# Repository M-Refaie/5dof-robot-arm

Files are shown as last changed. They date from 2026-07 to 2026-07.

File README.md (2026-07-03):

# 5-DOF Visual-Inspection Robotic Arm

A 5-degree-of-freedom robotic arm for automated visual inspection, combining servo-actuated joints, a rack-and-pinion rotating base (270° coverage), and an ESP32-CAM end-effector that recognizes targets on-device. Built end-to-end: mechanical design, custom electronics, kinematics & control, and an embedded AI vision model.

> Team project at Ain Shams University (Mechatronic System Design / Industrial Robotics, 2025). See *Credits*.

---

## Demo
▶ **[Watch the real arm run the full integrated system (video)](https://drive.google.com/file/d/1G8d9McYiD0UEVgwIUuDRzAie-aXbsvC7/view)**

Simulation (MATLAB / Simscape Multibody):
- ▶ [Inspection motion around the product](docs/sim_inspection_motion.mp4)
- ▶ [Forward-kinematics Simscape model](docs/sim_forward_kinematics.mp4)

## Highlights
- **5-DOF manipulator** — servo joints + rack-and-pinion base giving **270° rotation** around the inspected product.
- **On-device AI vision** — an **Edge Impulse** model deployed on an **ESP32-CAM** recognizes **15 letter targets** under varying angle and lighting.
- **Closed-loop PID** joint control, tunable **in real time via Arduino IoT Cloud** (live Kp/Ki/Kd, setpoint, and angle feedback on a dashboard).
- **Full kinematics in MATLAB** — forward & inverse kinematics, joint-space trajectory planning, and rigid-body-tree modeling (Simulink + Peter Corke Robotics Toolbox).
- **Custom hardware** — designed PCBs, 3D-printed joints/holders, and actuator sizing validated against MATLAB torque simulation.

## Tech stack
**Modeling & control:** MATLAB, Simulink, Peter Corke Robotics Toolbox, PID
**Embedded:** Arduino (C/C++), ESP32, ESP32-CAM, Arduino IoT Cloud
**AI/vision:** Edge Impulse (on-device inference)
**Hardware:** Autodesk Inventor (CAD), custom PCB, 3D printing
**Actuators/drivers:** DC motors w/ encoders (JGB-520), MG996 servos, L298N (DC), PCA9685 (servo)

## Robot parameters (standard DH)
| Joint | θ | d (mm) | a (mm) | α |
|---:|:--:|:---:|:---:|:----:|
| 1 | θ₁ | 65 | 277 | 90° |
| 2 | θ₂ | −37.5 | 192 | 0° |
| 3 | θ₃ | 17.5 | 172 | −90° |
| 4 | θ₄ | 0 | 62.5 | 90° |
| 5 | θ₅ | 0 | 45 | 0° |

## Repository structure
```
matlab/
├── peter_corke/        # forward/inverse kinematics (Peter Corke Toolbox)
├── simscape_sim/       # Simscape robot model + data files
└── simulink_control/   # cascaded control, DAQ, ESP32 motor block
firmware/
├── controlWithPot/       # PID joint control from a potentiometer setpoint
├── controlWithSetpoint/  # PID joint control from a fixed setpoint
└── arduino_iot_cloud/    # full ESP32 app: servo + DC PID + Arduino IoT Cloud dashboard
hardware/               # custom PCBs (Fritzing): base, DC, servo
docs/                   # dashboard screenshot
```

## Implementation
Key parts of the build:
- **Forward & inverse kinematics** and **joint-space trajectory planning** (Simulink + Peter Corke Robotics Toolbox), with rigid-body-tree modeling.
- **PID control** — designed/simulated in MATLAB/Simulink **and** implemented in Arduino firmware (encoder feedback + H-bridge, `PID_v1`).
- **Actuator sizing** from MATLAB torque simulation (RMS torque vs. selected motors/servos).
- **Custom PCB design** integrating the microcontroller, motor drivers (L298N / PCA9685), and power.
- **Integrated ESP32 application** tying the servo and DC-motor PID control together with a live Arduino IoT Cloud dashboard (`firmware/arduino_iot_cloud/`).

## Live control dashboard (Arduino IoT Cloud)
The arm connects to an **Arduino IoT Cloud** dashboard for live monitoring and tuning: the PID gains (Kp/Ki/Kd for both DC joints), servo and DC-motor setpoints, live joint-angle gauges, limit-switch status, and an automatic/manual mode switch, all adjustable in real time while the arm runs.

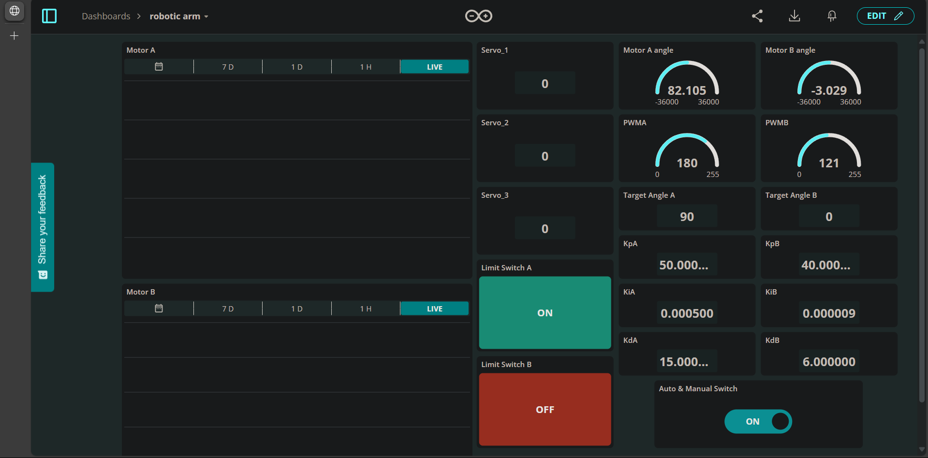
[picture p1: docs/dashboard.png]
Arduino IoT Cloud dashboard


Firmware in [`firmware/arduino_iot_cloud/`](firmware/arduino_iot_cloud): open `Main_Code.ino`, fill your network and device credentials into `arduino_secrets.h`, select the ESP32 board, and flash.

## Design (CAD)
The full test rig: the arm sits on a 270° curved rack that carries it around the inspected product, with the electronics box and power supply alongside.

| Full assembly | Inspection pose | End-effector |
|:--:|:--:|:--:|
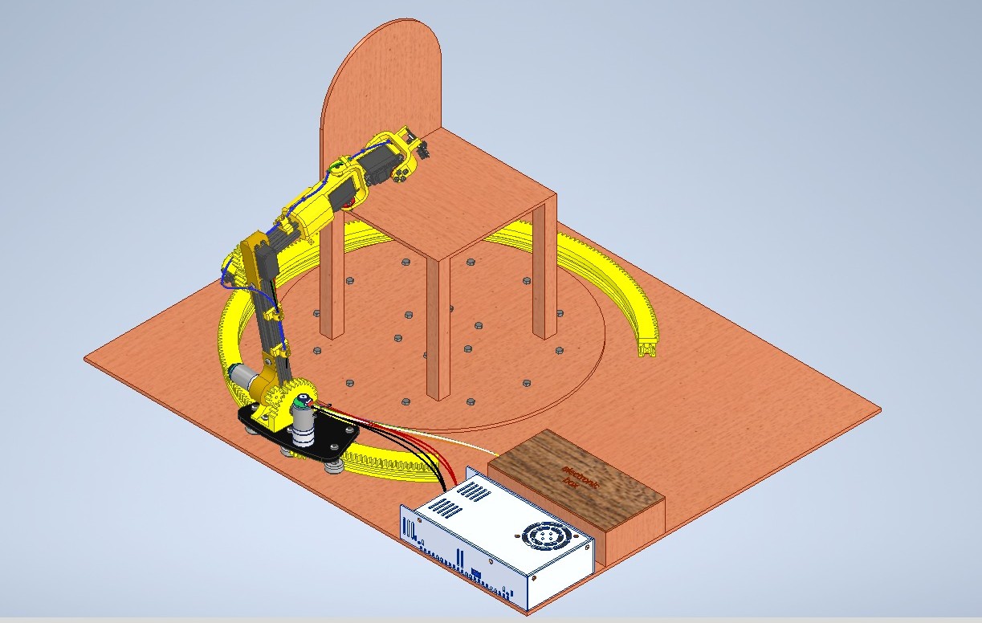
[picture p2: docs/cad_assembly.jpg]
Full CAD assembly of the arm and its test rig
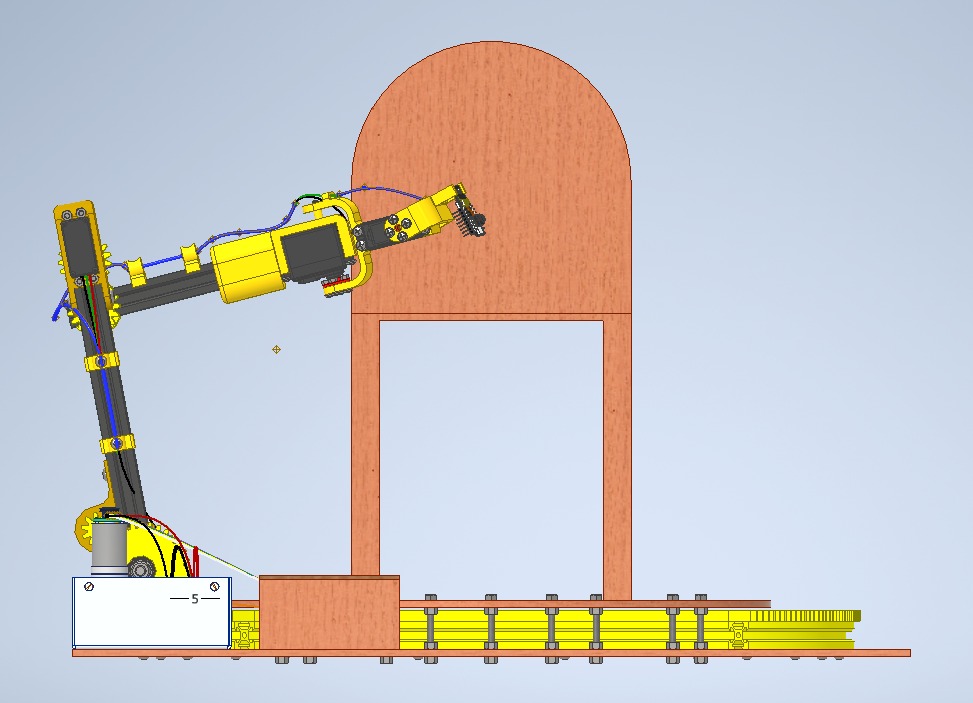
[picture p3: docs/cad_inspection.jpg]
Arm reaching an inspection pose
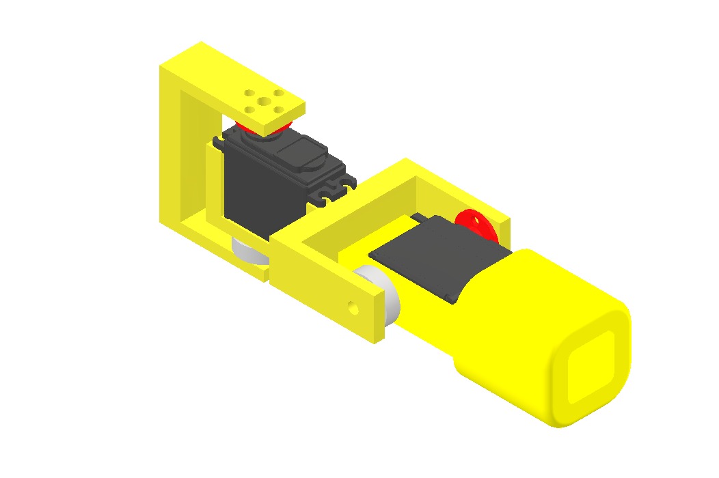
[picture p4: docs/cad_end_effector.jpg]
Wrist and ESP32-CAM end-effector
|  |  |  |

## Results
- 270° inspection sweep with repeatable joint positioning under PID control.
- On-device letter recognition across 15 classes (dataset reduced from 28→15 to fit the ESP32-CAM memory budget while keeping accuracy).

## How to run
- **MATLAB:** install the Peter Corke Robotics Toolbox, open `matlab/`, run the FK/IK scripts and the Simulink model.
- **Firmware:** open a sketch in `firmware/` in Arduino IDE (the full app is `firmware/arduino_iot_cloud/Main_Code.ino`), fill in `arduino_secrets.h`, select the ESP32 board, and flash.

## Credits
Team project at Ain Shams University (Mechatronics, 2025): Mohamed Refaie, Mina Ashraf, Mario Medhat, Mazen Mohamed, and Mariam Mahmoud.

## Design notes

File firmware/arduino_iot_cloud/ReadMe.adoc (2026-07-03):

:Author: mms13
:Email:
:Date: 01/05/2025
:Revision: version#
:License: Public Domain

= Project: {Project}

Describe your project

== Step 1: Installation
Please describe the steps to install this project.

For example:

1. Open this file
2. Edit as you like
3. Release to the World!

== Step 2: Assemble the circuit

Assemble the circuit following the diagram layout.png attached to the sketch

== Step 3: Load the code

Upload the code contained in this sketch on to your board

=== Folder structure

....
 sketch123                => Arduino sketch folder
  ├── sketch123.ino       => main Arduino file
  ├── schematics.png      => (optional) an image of the required schematics
  ├── layout.png          => (optional) an image of the layout
  └── ReadMe.adoc         => this file
....

=== License
This project is released under a {License} License.

=== Contributing
To contribute to this project please contact: 

=== BOM
Add the bill of the materials you need for this project.

|===
| ID | Part name      | Part number | Quantity
| R1 | 10k Resistor   | 1234-abcd   | 10       
| L1 | Red LED        | 2345-asdf   | 5        
| A1 | Arduino Zero   | ABX00066    | 1        
|===

=== Help
This document is written in the _AsciiDoc_ format, a markup language to describe documents. 
If you need help you can search the http://www.methods.co.nz/asciidoc[AsciiDoc homepage]
or consult the http://powerman.name/doc/asciidoc[AsciiDoc cheatsheet]

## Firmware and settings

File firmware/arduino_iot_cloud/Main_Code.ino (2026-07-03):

#include "arduino_secrets.h"
#include <Arduino.h>
#include "thingProperties.h"
#include <ESP32Servo.h>
#include <Wire.h>
#include <Adafruit_PWMServoDriver.h>

// Initialize the PWM Servo Driver at address 0x40
Adafruit_PWMServoDriver board1 = Adafruit_PWMServoDriver(0x40);

// Define the pulse range for each servo
int SERVOMIN[3] = {105,150,150}; // Minimum pulse length count (out of 4096)
int SERVOMAX[3] = {500,460,420}; // Maximum pulse length count (out of 4096)
int SERVORANGE[3] = {180,180,90}; // Servo angle range for each servo

#define SERVO_FREQ 50 // Frequency of the servos (50 Hz)

// Pin Definitions for limit switches
const int limitSwitchPinA = 2; 
const int limitSwitchPinB = 15; 
bool HomedA = 0; // Flag to check if Motor A has been homed
bool HomedB = 0; // Flag to check if Motor B has been homed

// Servo angles (initial values)
int angle1 = 90;  
int angle2 = 90;
int angle3 = 00;
const int angleinil = 90; // Initial servo angle

// Motor A Pins (DC Motor A)
static const int PWM_PIN_A = 18;
static const int IN1_PIN_A = 25;
static const int IN2_PIN_A = 26;
static const int ENCA_PIN_A = 35;
static const int ENCB_PIN_A = 34;

// Motor B Pins (DC Motor B)
static const int PWM_PIN_B = 19;
static const int IN1_PIN_B = 27;
static const int IN2_PIN_B = 14;
static const int ENCA_PIN_B = 33; 
static const int ENCB_PIN_B = 32; 

// PWM Configuration
#define CH_A 0
#define CH_B 1  
const uint32_t LEDC_FREQ = 5000; // Frequency for PWM signals
const int LEDC_RES = 8; // Resolution of PWM

// PID Variables
volatile long encoderPosA = 0, encoderPosB = 0; // Encoder positions for motors A and B
long prevMicros = 0; // Previous time for PID calculation
float prevErrorA = 0, prevErrorB = 0; // Previous error for PID
float integralA = 0, integralB = 0; // Integral error for PID

// Target & Conversion
const float PULSES2DEG_A = 180.0 / 11560.0;  // Conversion factor for Motor A
const float PULSES2DEG_B = 1296.0 / 22253.0; // Conversion factor for Motor B

// Motor Related Variables
int dirA; // Direction of Motor A
int dirB; // Direction of Motor B
float angleA; // Current angle of Motor A
float angleB; // Current angle of Motor B
long pulsesA; // Pulses for Motor A
long pulsesB; // Pulses for Motor B
int pwmA; // PWM value for Motor A
int pwmB; // PWM value for Motor B
float errorA; // Error for Motor A PID
float errorB; // Error for Motor B PID
float dA; // Derivative term for Motor A PID
float dB; // Derivative term for Motor B PID
float dt; // Time difference for PID
float uA; // Control output for Motor A PID
float uB; // Control output for Motor B PID

// Encoder Interrupt Service Routines (ISRs)
void IRAM_ATTR readEncoderA() {
    if (digitalRead(ENCB_PIN_A) == digitalRead(ENCA_PIN_A)) encoderPosA++;
    else encoderPosA--;  // Update encoder position for Motor A based on the direction
}

void IRAM_ATTR readEncoderB() {
    if (digitalRead(ENCB_PIN_B) == digitalRead(ENCA_PIN_B)) encoderPosB++;
    else encoderPosB--;  // Update encoder position for Motor B based on the direction
}

void IRAM_ATTR stopMotorA() {
    driveMotor(CH_A, IN1_PIN_A, IN2_PIN_A, 0, 0); 
    encoderPosA = 0; // Reset encoder position for Motor A
    angleA = 0; // Reset angle for Motor A
    currentAngle1 = 0; // Reset current angle for Servo 1
}

void IRAM_ATTR stopMotorB() {
    driveMotor(CH_B, IN1_PIN_B, IN2_PIN_B, 0, 0); 
    encoderPosB = 0; // Reset encoder position for Motor B
    angleB = 0; // Reset angle for Motor B
    currentAngle2 = 0; // Reset current angle for Servo 2
}

// Motor Driver Function to control direction and speed
void driveMotor(int pwmChannel, int in1, int in2, int dir, int pwmVal) {
  ledcWrite(pwmChannel, pwmVal); // Set the PWM value
  if (dir > 0) { // Forward direction
    digitalWrite(in1, LOW); 
    digitalWrite(in2, HIGH);
  }
  else if (dir < 0) { // Reverse direction
    digitalWrite(in1, HIGH);
    digitalWrite(in2, LOW);
  }
  else { // Stop the motor
    digitalWrite(in1, HIGH);
    digitalWrite(in2, HIGH);
  }
}

// Function to convert servo angle to PWM pulse width
void SetServoAngle(int servonum, int angle){
  board1.setPWM((servonum+8), 0, map(angle, 0, SERVORANGE[servonum], SERVOMIN[servonum], SERVOMAX[servonum]));
}

//////////////////////////\\\\\\\\\\\\\\\\\\\\\\\\\\
///////////////////// Scenario \\\\\\\\\\\\\\\\\\\\
//////////////////////////\\\\\\\\\\\\\\\\\\\\\\\\\\

// Define stop position
#define Stop_At_Pose_No 66

// Scenario array defines the sequence of poses
int Scenario[100][5] = { 
    {  0,  0,  90,  90,    0},
    {  0,  45,  90, 120,   5},
    // A
    {  0,  45,  70, 120,   5},
    {  0,  45,  70, 120,   5},
    {  0,  45,  70, 120,   5},
    // B
    {  0,  45,  25, 120,   5},
    {  0,  45,  25, 120,   5},
    {  0,  45,  25, 120,   5},
    // C
    {  0,  30,  65, 110,   0},
    {  0,  30,  65, 110,   0},
    {  0,  30,  65, 110,   0},
    // D
    {  0,  15,  80, 130,   0},
    {  0,  25,  80, 170,  20},
    {  0,  25,  80, 170,  20},
    // AWAY
    {  0,   0, 180,  90,  10},
    {  0,   0, 180,  90,  90},
    // E
    {  0,  40, 150,  70,  90},
    {  0,  40, 150,  35,  90},
    {  0,  40, 150,  35,  90},
    {  0,  40, 150,  35,  90},                //20
    // F
    {  0,  40,  60,  10,  90},
    {  0,  40,  60,  10,  90},
    // G
    { 10,  40,  60,  10,  90},
    { 20,  40,  55,  15,  90},
    { 30,  40,  50,  20, 80},
    { 30,  40,  45,  25, 70},
    { 30,  55,  35,  30, 65},
    { 30,  55,  35,  30, 65},
    { 30,  55,  35,  30, 65},
    // AWAY
    { 30,  40,   0,  50,  80},
    { 30,  20,   0,  50,  90},
    { 30,   0,   0,  50,  90},
    { 30,   0,   0,  90,   0},
    // Long Travel
    {  50,   0,   0,  90,  20},          
    {  70,   0,  20,  90,  20},          
    {  90,   0,  20,  90,  20},          
    { 110,   0,  20,  90,  20},          
    { 110,   0,  20,  90,  20},          
    { 110,   0,  20,  90,  20},          
    // H
    { 110,   0,  50, 125,  30},          
    { 110,   0,  80, 160,  40},          
    { 110,   0,  80, 160,  40},         
    { 110,   0,  80, 160,  40},         
    { 130,   0,  80, 160,  20},          
    { 150,   0,  80, 160,  20},          
    { 170,   0,  80, 160,  20},          // 46
    // More moves...
};

// Function to move to a specific pose in the scenario
void GoToPose(int currentPose){
    dc1    = Scenario[currentPose][0];  // Motor 1 angle for pose i
    dc2    = Scenario[currentPose][1];  // Motor 2 angle for pose i
    angle1 = Scenario[currentPose][2];  // Motor 3 angle for pose i
    angle2 = Scenario[currentPose][3];  // Motor 4 angle for pose i
    angle3 = Scenario[currentPose][4];  // Motor 5 angle for pose i  
}

// Variables to track time and pose
unsigned long lastMoveTime = 0;   // Store the last time a move was made
int currentPose = 0;               // Track the current pose

// Move function that progresses through the scenario
void Move() {
  unsigned long currentMillis = millis();
     PID_CHECK();

  if (currentMillis - lastMoveTime >= 1500) {  // Check if 1 second has passed
    lastMoveTime = currentMillis;  // Update the time for the next move
     PID_CHECK();
     GoToPose(currentPose); // Move to the next pose
     PID_CHECK();
     if((errorA<5)&&(errorB<5)){
       if (currentPose <= Stop_At_Pose_No)  currentPose++; // Proceed to next pose if error is small
     }  
  }
}

// PID control loop for Motor A and Motor B
void PID_CHECK()
{
 long now = micros();
  dt = (now - prevMicros) * 1e-6; // Time difference for PID calculation
  prevMicros = now;
  // PID Control for Motor A
   errorA = dc1 - angleA;
   dA = (errorA - prevErrorA) / dt; // Derivative term
  integralA += errorA * dt; // Integral term
  prevErrorA = errorA;
  uA = kpA * errorA + kiA * integralA + kdA * dA ; // PID output for Motor A
  pwmA = constrain((int)fabs(uA), 0, 180); // Constrain PWM value
  dirA = (uA > 0 ? 1 : (uA < 0 ? -1 : 0)); // Direction of Motor A
  
  if (fabs(errorA) <= 4.0) { // Stop Motor A if error is small
    pwmA = 0;
    dirA = 0;
    errorA = 0;
  }

  // PID Control for Motor B
   errorB = dc2 - angleB;
  dB = (errorB - prevErrorB) / dt;
  integralB += errorB * dt;
  prevErrorB = errorB;
  uB = kpB * errorB + kiB * integralB + kdB * dB; // PID output for Motor B
  pwmB = constrain((int)fabs(uB), 0, 180); // Constrain PWM value
  dirB = (uB > 0 ? 1 : (uB < 0 ? -1 : 0)); // Direction of Motor B
  
  if (fabs(errorB) <= 2.0) { // Stop Motor B if error is small
    pwmB = 0;
    dirB = 0;
    errorB = 0;
  }

    // Drive Motors
  driveMotor(CH_A, IN1_PIN_A, IN2_PIN_A, dirA, pwmA);
  driveMotor(CH_B, IN1_PIN_B, IN2_PIN_B, dirB, pwmB);
};

// Setup function for initial configurations
void setup() {
  Serial.begin(115200);
  delay(1500);
  
  // Initialize PWM Servo Driver
  board1.begin();
  board1.setOscillatorFrequency(27000000);
  board1.setPWMFreq(SERVO_FREQ);  // Analog servos run at ~50 Hz updates
  delay(100);
  
  // Pin Modes for limit switches and motor pins
  pinMode(limitSwitchPinA, INPUT_PULLUP);
  pinMode(limitSwitchPinB, INPUT_PULLUP);
  pinMode(IN1_PIN_A, OUTPUT);
  pinMode(IN2_PIN_A, OUTPUT);
  pinMode(IN1_PIN_B, OUTPUT);
  pinMode(IN2_PIN_B, OUTPUT);

  // PWM Setup for Motors A and B
  ledcSetup(CH_A, LEDC_FREQ, LEDC_RES);
  ledcAttachPin(PWM_PIN_A, CH_A);
  ledcSetup(CH_B, LEDC_FREQ, LEDC_RES);
  ledcAttachPin(PWM_PIN_B, CH_B);

  // Encoder Setup
  pinMode(ENCA_PIN_A, INPUT_PULLUP);
  pinMode(ENCB_PIN_A, INPUT_PULLUP);
  pinMode(ENCA_PIN_B, INPUT_PULLUP);
  pinMode(ENCB_PIN_B, INPUT_PULLUP);
  
  attachInterrupt(digitalPinToInterrupt(ENCA_PIN_A), readEncoderA, RISING);
  attachInterrupt(digitalPinToInterrupt(ENCA_PIN_B), readEncoderB, RISING);

  prevMicros = micros();

  // Initialize Arduino IoT Cloud
  initProperties();
  ArduinoCloud.begin(ArduinoIoTPreferredConnection);
  setDebugMessageLevel(2);
  ArduinoCloud.printDebugInfo();

  // Homing initialization
  HomedA = 0;
  HomedB = 0;
}

// Main loop function
void loop() {
  ArduinoCloud.update(); // Update IoT Cloud variables
   pulsesA = encoderPosA; // Update encoder pulses for Motor A
   pulsesB = encoderPosB; // Update encoder pulses for Motor B
  interrupts(); // Enable interrupts
  if (HomedA == 0)  dc1 = -500; // Move Motor A to home position if not already homed
  limit_switch_state = digitalRead(limitSwitchPinA); // Read limit switch for Motor A
  limit_switch_state1 = digitalRead(limitSwitchPinB); // Read limit switch for Motor B
   angleA = pulsesA * PULSES2DEG_A; // Calculate angle of Motor A
   angleB = pulsesB * PULSES2DEG_B; // Calculate angle of Motor B
  if ((limit_switch_state == 0) && (dc1 <= angleA)){ // If limit switch for Motor A is pressed
    pulsesA = 0;
    dc1 = 0;
    HomedA = 1;
    driveMotor(CH_A, IN1_PIN_A, IN2_PIN_A, 0, 0); // Stop Motor A
    angleA = 0;
  }

  if(_switch_){Move();} // For Switch between Automatic & Manual Control
  // Update servo positions
  SetServoAngle(0, angle1);
  SetServoAngle(1, angle2);
  SetServoAngle(2, angle3);
  // Update DC Motor Positions
  PID_CHECK(); 
  // Update Cloud Variables
  pWMA = pwmA * dirA;
  pWMB = pwmB * dirB;
  currentAngle1 = angleA;
  currentAngle2 = angleB;
}

// IoT Cloud Callbacks (ensure these match your thingProperties.h)
void onDc1Change() { Serial.print("Target A:"); Serial.println(dc1); }
void onDc2Change() { Serial.print("Target B:"); Serial.println(dc2); }
void onKpAChange() { Serial.print("KpA:"); Serial.println(kpA); }
void onKpBChange() { Serial.print("KpB:"); Serial.println(kpB); }
void onKiAChange() { Serial.print("KiA:"); Serial.println(kiA); }
void onKiBChange() { Serial.print("KiB:"); Serial.println(kiB); }
void onKdAChange() { Serial.print("KdA:"); Serial.println(kdA); }
void onKdBChange() { Serial.print("KdB:"); Serial.println(kdB); }
void onS1Change() { angle1 = s1; Serial.print("Servo1:"); Serial.println(angle1); }
void onS2Change() { angle2 = s2; Serial.print("Servo2:"); Serial.println(angle2); }
void onS3Change() { angle3 = s3; Serial.print("Servo3:"); Serial.println(angle3); }
void onPWMAChange() { /* Handle if needed */ }
void onPWMBChange() { /* Handle if needed */ }
void onSwitchChange()  {/* Handle if needed */ }

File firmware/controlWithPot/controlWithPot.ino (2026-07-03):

#include <PID_v1.h>

// Motor Control Pins
#define IN1       6
#define IN2       7
#define ENA       5

// Encoder Pins
#define ENCODER_A 2
#define ENCODER_B 3

// Potentiometer Pin
#define POT_PIN   A0

// PID Constants (tune these)
double Kp = 1.2;
double Ki = 0.085;
double Kd = 1.0;

// PID Variables
double Setpoint = 0.0;    // will be set from pot
double Input;             // Measured position (°)
double Output;            // PID output (-255…255)

PID myPID(&Input, &Output, &Setpoint, Kp, Ki, Kd, DIRECT);

volatile long encoderPos = 0;
const float degreesPerPulse = 360.0 / 11560.0;  // set to your encoder CPR×gear ratio

void setup() {
  Serial.begin(9600);

  // Print header for Serial Plotter once
  Serial.println("Setpoint Input Output");

  // Motor pins
  pinMode(IN1, OUTPUT);
  pinMode(IN2, OUTPUT);
  pinMode(ENA, OUTPUT);

  // Encoder pins
  pinMode(ENCODER_A, INPUT_PULLUP);
  pinMode(ENCODER_B, INPUT_PULLUP);
  attachInterrupt(digitalPinToInterrupt(ENCODER_A), updateEncoder, CHANGE);

  // Potentiometer input
  pinMode(POT_PIN, INPUT);

  // PID setup
  myPID.SetMode(AUTOMATIC);
  myPID.SetOutputLimits(-255, 255);
}

void loop() {
  // 1) Read potentiometer and map 0–1023 to 0–360°
  int potRaw = analogRead(POT_PIN);
  Setpoint = (potRaw / 1023.0) * 360.0;

  // 2) Convert encoder count to degrees
  noInterrupts();
    long counts = encoderPos;
  interrupts();
  Input = counts * degreesPerPulse;

  // 3) Compute PID
  myPID.Compute();

  // 4) Drive motor
  if (Output > 0) {
    digitalWrite(IN1, HIGH);
    digitalWrite(IN2, LOW);
    analogWrite(ENA, (int)Output);
  } else if (Output < 0) {
    digitalWrite(IN1, LOW);
    digitalWrite(IN2, HIGH);
    analogWrite(ENA, (int)(-Output));
  } else {
    analogWrite(ENA, 0);
  }

  // 5) Send data for Serial Plotter
  //    Format: Setpoint<space>Input<space>Output<newline>
  Serial.print(Setpoint, 1);
  Serial.print(" ");
  Serial.print(Input, 1);
  Serial.print(" ");
  Serial.println(Output, 1);

  delay(10);  // adjust loop rate if needed
}

void updateEncoder() {
  // Quadrature decode on A-change
  if (digitalRead(ENCODER_A) == digitalRead(ENCODER_B))
    encoderPos++;
  else
    encoderPos--;
}
